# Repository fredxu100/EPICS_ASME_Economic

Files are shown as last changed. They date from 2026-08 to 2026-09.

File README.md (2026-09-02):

# EPICSxASME Hydroponics Repository

## 1. Overview
<p align="center">
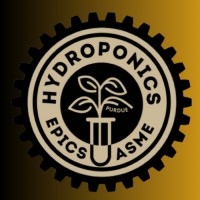
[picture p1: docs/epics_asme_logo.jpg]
  
</p>

THIS IS A TEMPORARY REPO UNTIL THE OWNERS OF MAIN https://github.com/PurdueASMEHydroponics/ASMExEPICS REPO ACCPET MY MERGE REQUEST

Repo for electrical for now, but structures can be included as well. Modify the README as you contribute.

Important information is found in the documentation folder, refer to the documentation readme for further info.

---

## 2. Contributing

Refer to and update Issues tab to organize work

### GitHub Desktop
Use to clone/contribute to this repository
[https://www.youtube.com/watch?v=8Dd7KRpKeaE](url)

### Altium
Required to work on PCB files; obtain a student liscense
Student liscense download tutorial: https://www.youtube.com/watch?v=OIAWbNRDB1U
Copy video project to learn Altium: https://www.youtube.com/watch?v=YTGzncKU5RY 

### Arduino IDE
Required to modify/update firmware; search for a download tutorial

---

## 3. Directory
```text
repository-name/
├── altium_files/       # .zip file to download onto Altium
├── docs/               # Documentation/guides
├── fabrication pack/   # JLPCB fabrication packages
├── firmware/           # Arduio scripts
└── README.md           # Project overview and usage guidelines

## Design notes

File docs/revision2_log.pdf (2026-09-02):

MAIN AND PERISTALTIC DATSHEETS
NKP-DC-S10B, Peristaltic
https://www.kamoer.cn/us/product/params.html?id=4004 Datasheet
- 800 Hour lifetime
- ~$16 x 3/2 = $24
- <12 watts, 4-14 mL/min (enough for nutrients)
- purchase link amazon (https://www.amazon.com/Kamoer-Peristaltic-Hydroponics-Nutrient-Analytical/dp/B0GZV4G8ZQ)

NOTE: BE SURE TO TEST SPECS OF CURRENT WATER PUMP

DEFENSIVE ELECTRICAL UPDATES
The prior system had no built-in defensive mechanisms and fault checks. Update will include

UPDATES
1) Shunt sensing: Built into main pump lines, program arduino to measure voltage/shut down FET if detecting anomaly
2) Red LEDs: When voltage is not at correct level, Arduino will output red warning light
3) Flyback diodes: Suppress voltage transients from pump inductance

PUMP SENSOR COUNT REDUCTION
Water level sensors should be simplified: Unnecessary to have multiple water level sensors if it’ll all be flowing anyways.

NOTE: MAKE SURE TO CONSIDER BLOCKAGES FOR WATER LEVEL SENSING
Only 1 needed at the top level, should be enough as long as structures account for drainage

UPDATES
1) Decreased water level sensing from 4 -> 1

PDN UPDATES
NOTE: Arduino nano takes in 7-12V, NOT 5V at Vin, allows for approx 0.5V dV drop, make sure Ztarget of PDN < 0.5V/transient

UPDATES
1) Decoupling network capacitances update
2) 5V buck regulator -> 7V buck regulator Vin
3) MBR745G -> MBR1060G diode for both flyback + buck regulator

https://docs.arduino.cc/hardware/nano/#tech-specs Nano datasheet

ELECTRICAL TO DO
1) Test maximum transients (with flyback included) for pumps, check if within FET tolerance
2) Structures team, update drainage system (due to water level sensor removal)
3) Measure impedance on all power traces, ensure power drop is within tolerance
4) Validate whether thermals will be an issue for PCB (specifically FET/diode/traces)

FIRMWARE TO DO
1) Organize files, basic EC + pH + water -> pumps control
2) Arduino program that detects voltage/current across shunts -> red LED
3) Overflow loop counter to defend against pump constantly pumping
4) Median value of ~5-10s of inputs in firmware to filter out analog signal noise

FUTURE UPDATES
1) Decentralize defense away from arduino (ex fuses, breakers)
2) Update if tolerances specifications are not met (V, Z, I, etc)

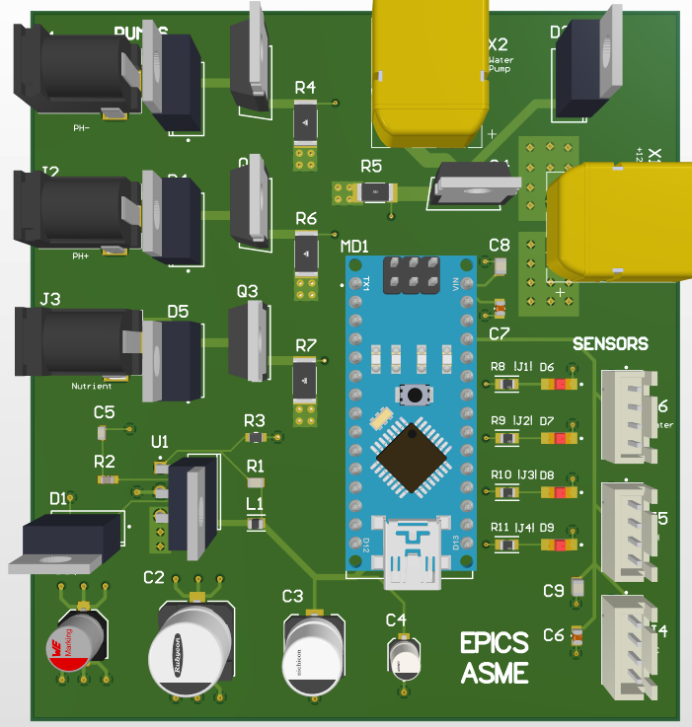
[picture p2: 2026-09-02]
docs/Design_2/3D_2.png

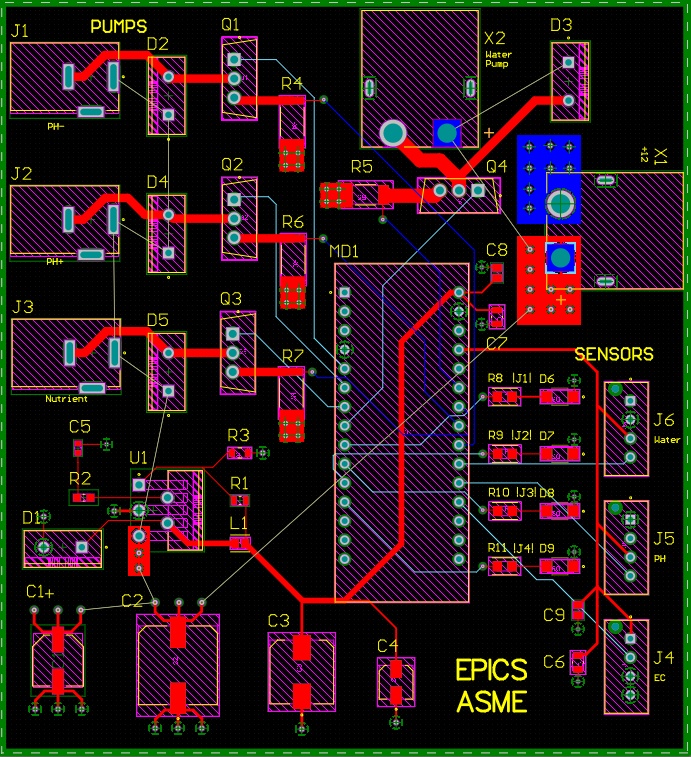
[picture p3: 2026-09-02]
docs/Design_2/Routing2.png

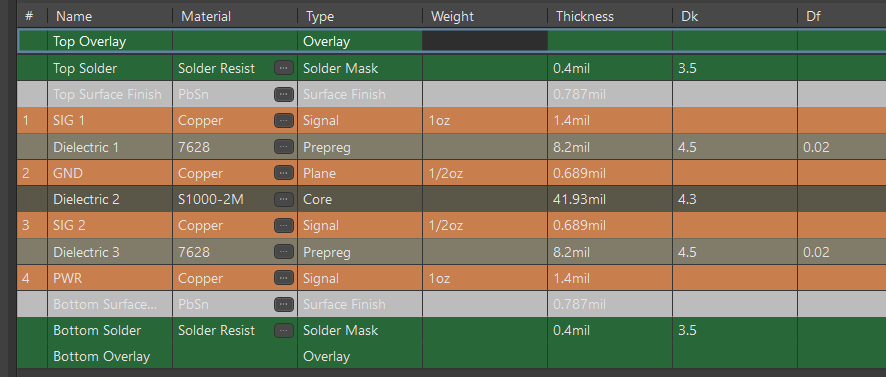
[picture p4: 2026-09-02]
docs/Design_2/stackup.png

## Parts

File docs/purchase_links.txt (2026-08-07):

**LINKS**
Main water pump, 72 Watts: 
https://www.amazon.com/Pressure-Diaphragm-Priming-Transfer-Suitable/dp/B0DJQ7MMKR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

Peristaltic pumps: 
https://amazon.com/Diitao-Peristaltic-Connector-Aquarium-Analytic/dp/B0BB7KFRKJ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

EC Sensor: 
https://www.amazon.com/Conductivity-Hydroponics-Waterproof-Monitoring-Detection/dp/B08SQGL728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

PH Sensor: 
https://www.amazon.com/Teyleten-Robot-Acquisition-Alkalinity-Monitoring/dp/B09H1MJS4S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

Water level sensors: 
https://www.amazon.com/DIYables-Detector-Arduino-ESP8266-Raspberry/dp/B0BXKMLB4D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

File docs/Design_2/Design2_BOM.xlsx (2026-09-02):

Line # | Name | Description | Designator | Revision ID | Revision State | Revision Status | Quantity | Manufacturer 1 | Manufacturer Part Number 1 | Manufacturer Lifecycle 1 | Supplier 1 | Supplier Part Number 1 | Supplier Unit Price 1 | Supplier Subtotal 1
 | 865060145006 | WCAP-ASLL Aluminum Electrolytic Capacitors | C1 | CMP-03913-53914500-3 | New From Design | Up to date | 1 | Wurth Elektronik | 865060145006 | Volume Production | DigiKey | 732-865060145006CT-ND | 0.37 | 0.37
 | 35TGV100M10X10.5 | CAP ALUM 100UF 20% 35V SMD | C2 | CMP-35376-000017-1 | New From Design | Up to date | 1 | Rubycon | 35TGV100M10X10.5 | Volume Production | Mouser | 232-35TGV100M10X10.5 | 1.4 | 1.4
 | UUX1H470MNL6GS | CAP ALUM 47UF 20% 50V SMD | C3 | CMP-12462-000056-1 | New From Design | Up to date | 1 | Nichicon | UUX1H470MNL6GS | Volume Production | DigiKey | 493-6272-1-ND | 0.57 | 0.57
 | EDK106M035A9BAA | CAP ALUM 10UF 20% 35V SMD | C4 | CMP-03015-000003-1 | New From Design | Up to date | 1 | Yageo Group | EDK106M035A9BAA | Volume Production | DigiKey | 399-14794-1-ND | 0.26 | 0.26
 | C0603S103K4RACTU |  | C5 | CMP-2006-03842-1 | Released | Up to date | 1 | Yageo Group | C0603S103K4RACTU | Volume Production | Mouser | 80-C0603S103K4R | 0.3 | 0.3
 | CC0805KKX5R6BB105 | CAP CER 1UF 10V X5R 0805 | C6, C7 | CMP-03422-000746-1 | New From Design | Up to date | 2 | Yageo Group | CC0805KKX5R6BB105 | Volume Production | Arrow Electronics | CC0805KKX5R6BB105 | 0.0239 | 0.0478
 | 08051C104M4Z2A |  | C8, C9 | CMP-2007-04740-1 | Released | Up to date | 2 | KYOCERA AVX | 08051C104M4Z2A | Volume Production | Newark | 08051C104M4Z2A | 0.195 | 0.39
 | MBR1060G | SWITCHMODE(TM) Power Rectifier, 2-Pin TO-220, Pb-Free, Tube | D1, D2, D3, D4, D5 | CMP-1055-00607-1 | Released | Up to date | 5 | onsemi | MBR1060G | Volume Production | Arrow Electronics | MBR1060G | 1.07 | 5.33
 | LTST-C230EKT | LED RED CLEAR CHIP SMD | D6, D7, D8, D9 | CMP-22017-000030-1 | New From Design | Up to date | 4 | Lite-On | LTST-C230EKT | Volume Production | DigiKey | 160-1187-1-ND | 0.19 | 0.76
 | PJ-002A | Through Hole Right Angle DC Power Jack, 2.5 A, 2 mm Center Pin, 3 Position, -25 to 85 degC, RoHS, Bulk | J1, J2, J3 | CMP-2000-06895-2 | Released | Up to date | 3 | Same Sky | PJ-002A | Volume Production | Mouser | 490-PJ-002A | 0.58 | 1.74
 | B4B-XH-AM (LF)(SN) | CONN HEADER VERT 4POS 2.5MM | J4, J5, J6 | CMP-17439-000117-1 | New From Design | Up to date | 3 | JST | B4B-XH-AM (LF)(SN) | Volume Production | Arrow Electronics | B4B-XH-AM(LF)(SN) | 0.1366 | 0.4098
 | LQM21DH101M70L | Multilayer type Inductor for Power Lines for Automotive 100uH ±20% @1MHz, 160mA, Max DCR 4.095Ω, SRF 8MHz | L1 | CMP-06042-017057-1 | New From Design | Up to date | 1 | Murata | LQM21DH101M70L | New Product | Mouser | 81-LQM21DH101M70L | 0.26 | 0.26
 | A000005 | ARDUINO NANO ATMEGA328 EVAL BRD | MD1 | CMP-189986-000002-1 | New From Design | Up to date | 1 | Arduino | A000005 | Unknown | Mouser | 782-A000005 | 22.53 | 22.53
 | IRLZ44NPbF | MOSFET N-CH 55V 47A TO220AB | Q1, Q2, Q3, Q4 | CMP-32901-000488-1 | New From Design | Up to date | 4 | Infineon | IRLZ44NPBF | Volume Production | Arrow Electronics | IRLZ44NPBF | 0.5273 | 5.27
 | RC0805JR-131KL |  | R1 | CMP-2001-01418-1 | Released | Up to date | 1 | Yageo Group | RC0805JR-131KL | Volume Production | Mouser | 603-RC0805JR-131KL | 0.1 | 0.1
 | 2K7 5% 0603(1608) | 2K7 0.1W 5% 0603 (1608 Metric) SMD | R2 | CMP-1012-00084-1 | Released | Up to date | 1 | Yageo Group | RC0603JR-072K7L | Volume Production | DigiKey | 311-2.7KGRDKR-ND | 0.1 | 0.1
 | AC0805JR-072K2L | RES SMD 2.2K OHM 5% 1/8W 0805 | R3 | CMP-03412-037614-1 | New From Design | Up to date | 1 | Yageo Group | AC0805JR-072K2L | Volume Production | Mouser | 603-AC0805JR-072K2L | 0.1 | 0.1
 | CRCW25121R00FKEH | RES Thick Film, 1Ω, 1%, 1W, 100ppm/°C, 2512 | R4, R6, R7 | CMP-02407-008720-1 | New From Design | Up to date | 3 | Vishay | CRCW25121R00FKEH | Volume Production | Mouser | 71-CRCW25121R00FKEH | 0.47 | 1.41
 | CSRN2010FTR100 | Res Thick Film 2010 0.1Ω 1% 1W ±250ppm/°C Molded SMD Plastic T/R | R5 | CMP-26527-001368-1 | New From Design | Up to date | 1 | Stackpole Electronics | CSRN2010FTR100 | Volume Production
 | RMCF0805JT220R | 220Ω ±5% 0.125W 0805 Thick Film Chip Resistor AEC-Q200 compliant | R8, R9, R10, R11 | CMP-26527-006932-1 | New From Design | Up to date | 4 | Stackpole Electronics | RMCF0805JT220R | Volume Production | Mouser | 708-RMCF0805JT220R | 0.014 | 0.14
 | LT1076IT | Step-Down Switching Regulator, 5-pin FM (T-5), -40 to 85 degC | U1 | CMP-0491-02059-1 | Released | Up to date | 1 | Analog Devices / Linear Technology | LT1076IT | Volume Production
 | X1 |  | X1 |  | Not managed |  | 1
 | X2 |  | X2 |  | Not managed |  | 1

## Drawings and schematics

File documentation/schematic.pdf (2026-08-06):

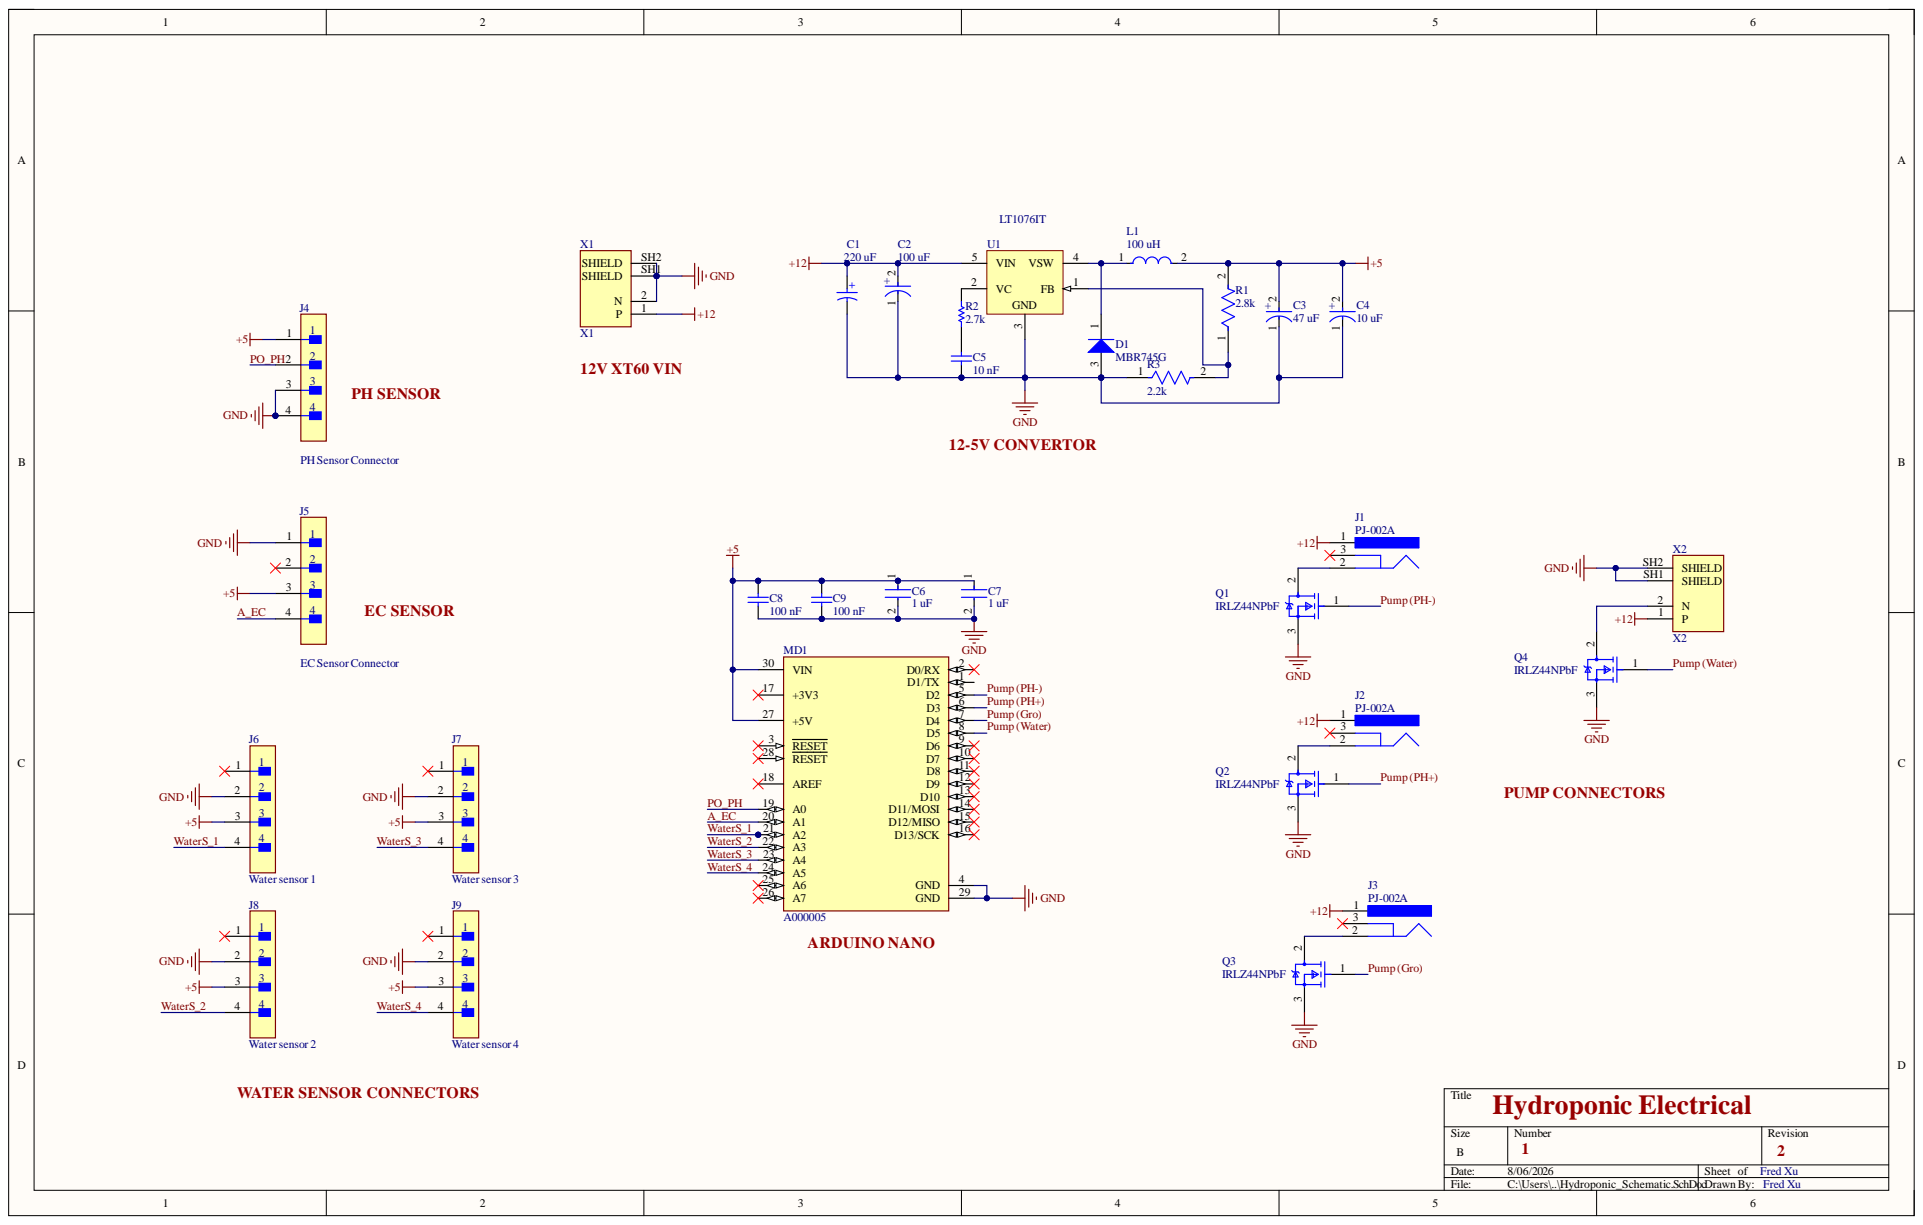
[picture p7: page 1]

Si z e | Num b er 1 | Revi s i on 2

e : 8/06/ 20 2 6 | Sheet of Fred X u
Fi l e : C : \U ser s \..\ Hydroponic_Schemat i c . S chDo | cD rawn By: Fred X u

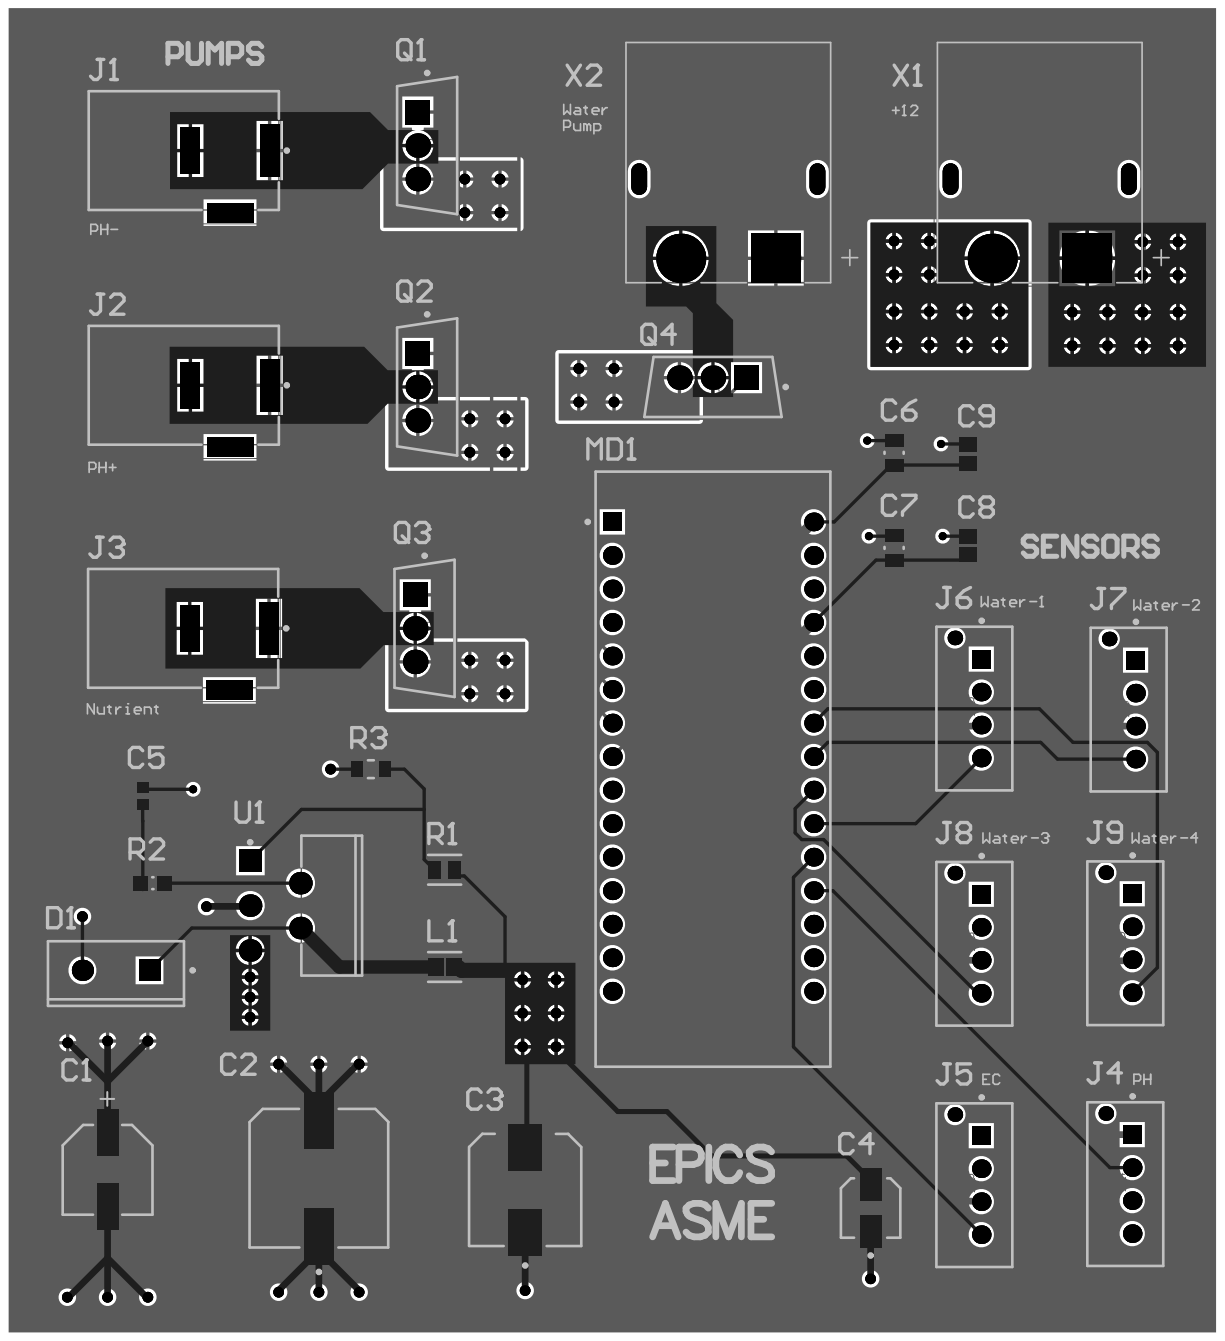
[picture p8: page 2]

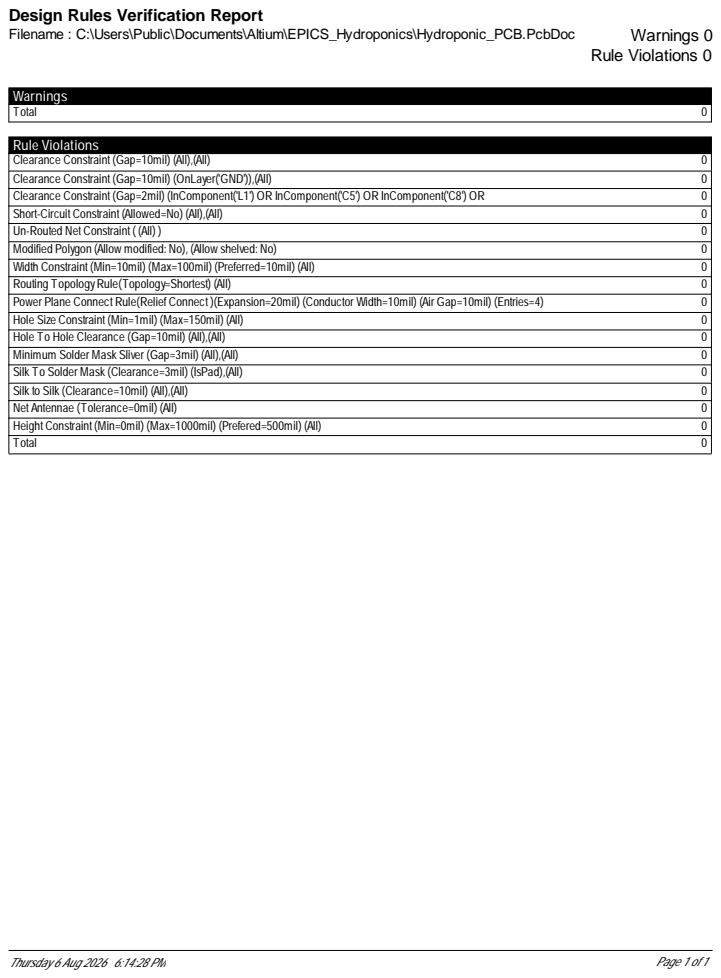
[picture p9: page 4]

Design Rules Verification Report

### Electrical Rules Check Report

Class | Document | Message
Warning | Hydroponic_Schematic.SchDoc | Net NetR1_1 has no driving source (Pin R1-1, Pin R3-2, Pin U1-1)
Thursday 6 Aug 2026 6:14:28 PM | Page 1 of 1

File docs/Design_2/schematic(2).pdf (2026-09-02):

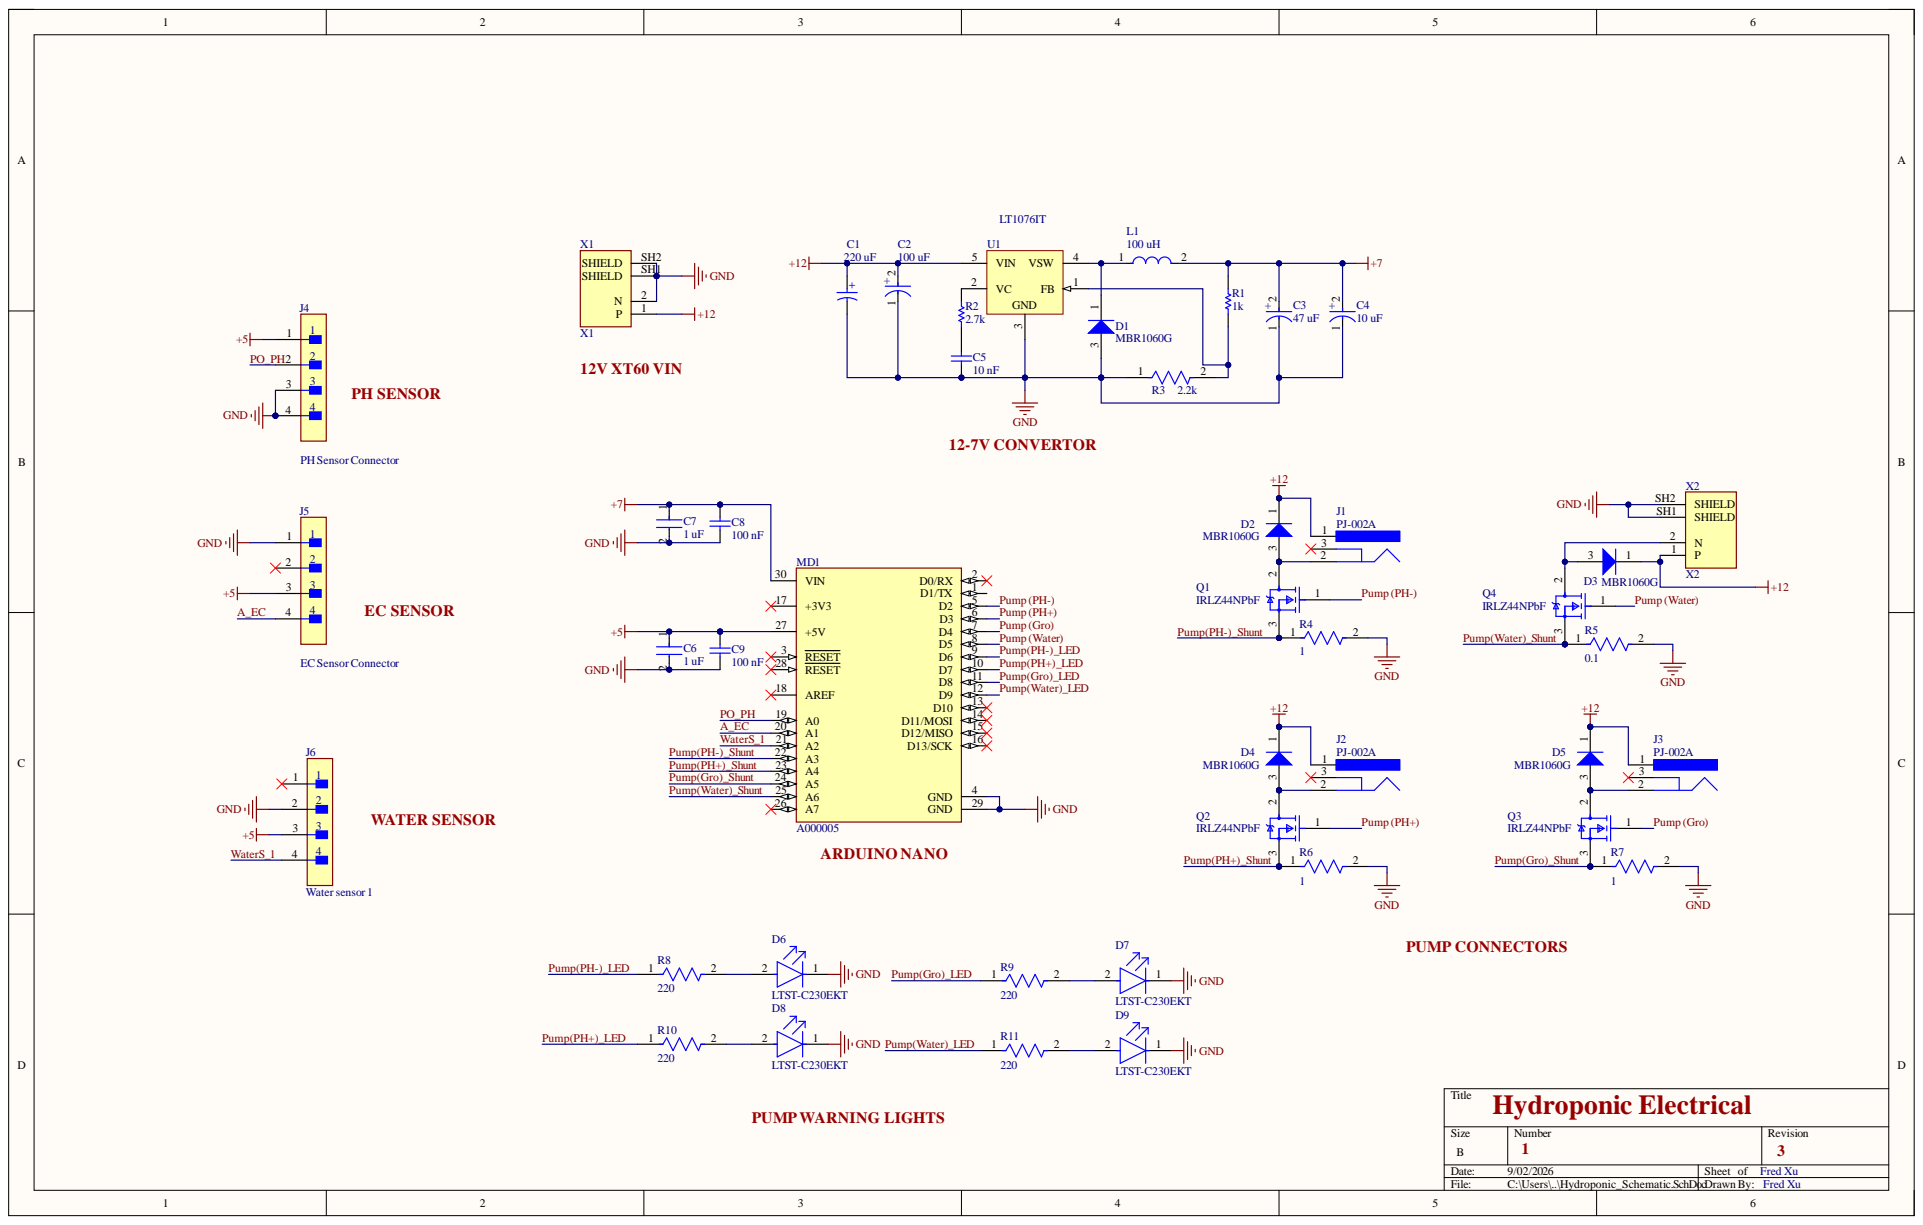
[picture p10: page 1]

Size B | Number 1 3 | Revision

Date: 9/02/2026 | Sheet of Fred Xu
File: C:\Users\..\Hydroponic_Schematic.SchDocDrawn By: | Fred Xu

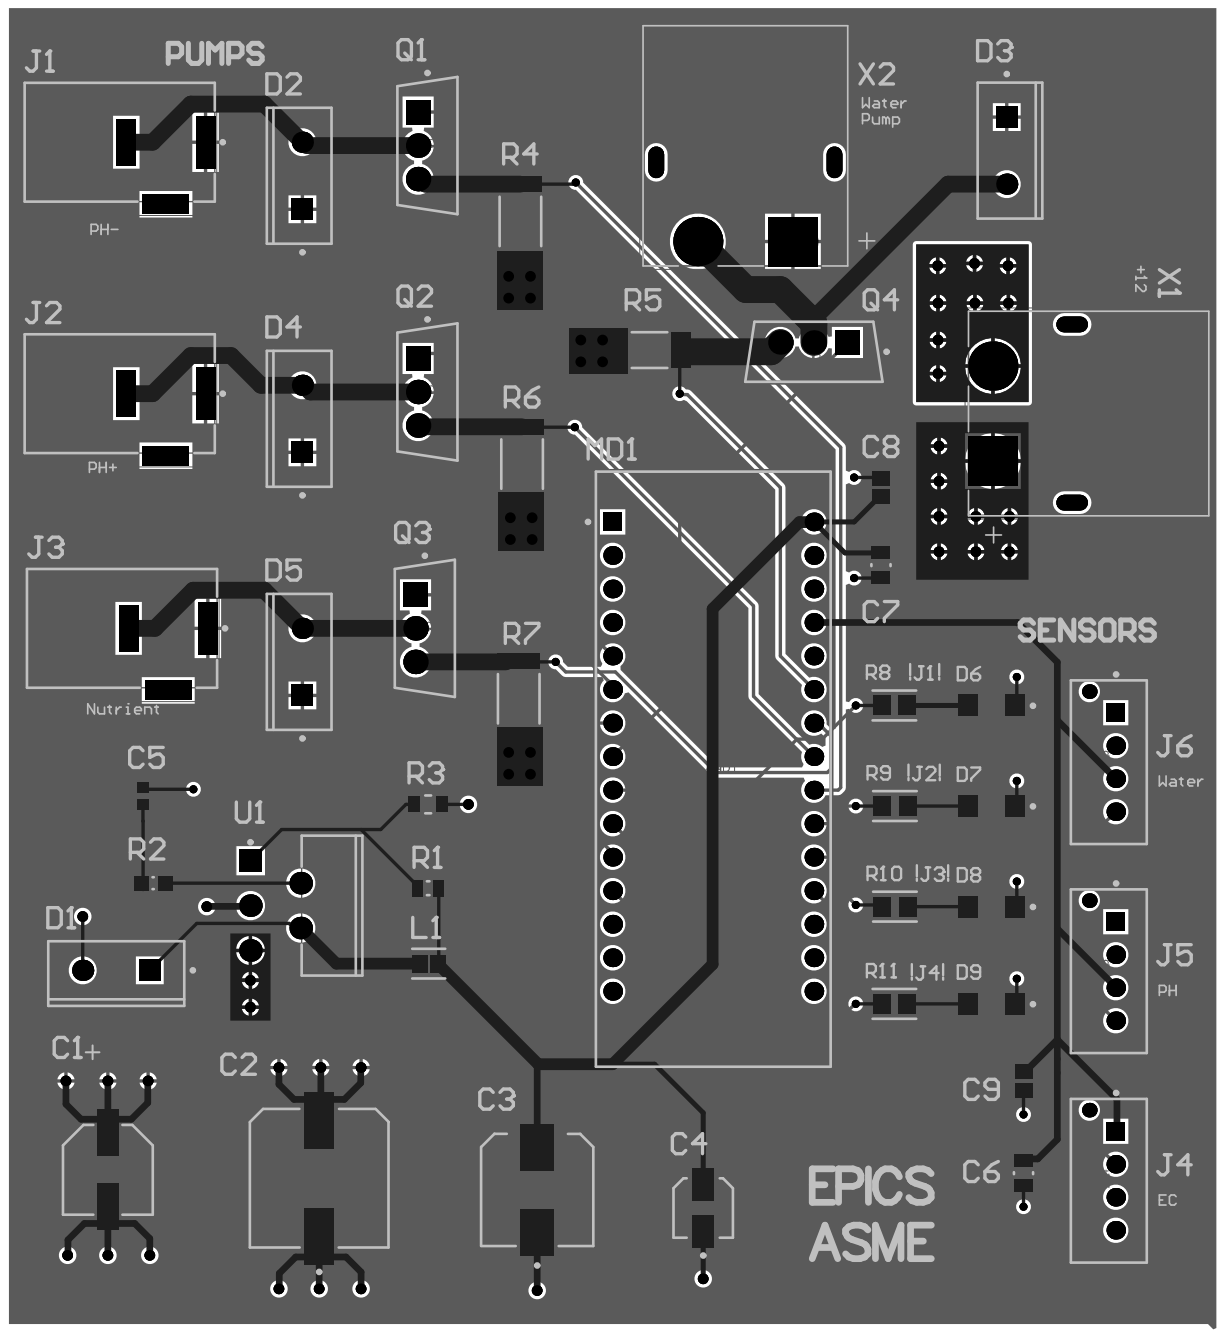
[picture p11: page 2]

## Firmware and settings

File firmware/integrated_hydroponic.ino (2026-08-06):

#include <SoftwareSerial.h>                           //we have to include the SoftwareSerial library, or else we can't use it
#define rx 2                                          //define what pin rx is going to be
#define tx 3                                          //define what pin tx is going to be

SoftwareSerial myserial(rx, tx);                      //define how the soft serial port is going to work

String inputstring = "";                              //a string to hold incoming data from the PC
String sensorstring = "";                             //a string to hold the data from the Atlas Scientific product
boolean input_string_complete = false;                //have we received all the data from the PC
boolean sensor_string_complete = false;               //have we received all the data from the Atlas Scientific product
float pH;                                             //used to hold a floating-point number that is the pH

unsigned long lastTime = 0;
int water_sensor_value = 0;

void setup()
{
  Serial.begin(9600);                                 //set baud rate for the hardware serial port_0 to 9600
  myserial.begin(9600);                               //set baud rate for the software serial port to 9600
  inputstring.reserve(10);                            //set aside some bytes for receiving data from the PC
  sensorstring.reserve(30);                           //set aside some bytes for receiving data from Atlas Scientific product

  pinMode(A0, INPUT);
  pinMode(12, OUTPUT);
  pinMode (11, OUTPUT);
}

void serialEvent()
{
  inputstring = Serial.readStringUntil(13);           //read the string until we see a <CR>
  input_string_complete = true;                       //set the flag used to tell if we have received a completed string from the PC
}


void loop()
{
  if (input_string_complete == true)                  //if a string from the PC has been received in its entirety
  {
    myserial.print(inputstring);                      //send that string to the Atlas Scientific product
    myserial.print('\r');                             //add a <CR> to the end of the string
    inputstring = "";                                 //clear the string
    input_string_complete = false;                    //reset the flag used to tell if we have received a completed string from the PC
  }

  if (myserial.available() > 0)                       //if we see that the Atlas Scientific product has sent a character
  {
    char inchar = (char)myserial.read();              //get the char we just received
    sensorstring += inchar;                           //add the char to the var called sensorstring
    if (inchar == '\r')                               //if the incoming character is a <CR>
    {
      sensor_string_complete = true;                  //set the flag
    }
  }

  if (sensor_string_complete == true)                 //if a string from the Atlas Scientific product has been received in its entirety
  {
    Serial.println("");
    Serial.print("PH Value: ");
    Serial.println(sensorstring);                     //send that string to the PC's serial monitor
    
    pH = sensorstring.toFloat();
    if (pH < 6.0 && pH > 0.0)                         //if pH is below 6 (and not a 0.0 error)
    {
      digitalWrite(11, HIGH);                         //turn on pin 10
    }
    else
    {
      digitalWrite(11, LOW);                          //turn off pin 10
    }
    
    
    sensorstring = "";                                //clear the string
    sensor_string_complete = false;                   //reset the flag used to tell if we have received a completed string from the Atlas Scientific product
  }

  if (millis() - lastTime >= 1000) {
      water_sensor_value = analogRead(A0);
      Serial.println();
      Serial.print("Water level value: ");
      Serial.print(water_sensor_value);
      lastTime = millis();
  }

  if (water_sensor_value >= 500)
  {
    digitalWrite(12, HIGH);
  }
  else
  {
    digitalWrite(12, LOW);
  }

}

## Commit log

2026-08-28 BOM csv
    [EPICS_Hydroponics_2.xlsx]
2026-09-02 revision 2 update
    [Design2_BOM.xlsx, EPICS_Hydroponics_2.xlsx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]
2026-09-06 fab updates
    [Hydroponic_PCB.GBL, Hydroponic_PCB.GBO, Hydroponic_PCB.GBP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]
